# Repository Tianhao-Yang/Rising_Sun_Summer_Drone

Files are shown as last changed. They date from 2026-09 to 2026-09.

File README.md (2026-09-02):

# Rising Sun Summer Drone

Rising Sun is a self-built quadcopter developed as a summer engineering project. It combines mechanical design, flight control, onboard computing, telemetry, data logging, and a custom ground-station system.

This repository contains three main components:

1. Ground station
2. CAD files
3. Raspberry Pi onboard system

## 1. Ground Station

The ground-station system includes a desktop application and an online website.

### Desktop Application

The desktop application was developed using Python and PySide6. It receives MAVLink telemetry from the Pixhawk and live video from the onboard camera through a VTX system.

The application is organized into three pages:

- **Home:** Project overview, interactive 3D drone model, flight-log list, recorded videos, and telemetry-data viewer.
- **Flight Display:** Live camera feed, with a HUD display, flight instruments, motor and battery monitoring, system status, flight-phase checklists, warnings, recording controls and map.
- **HUD:** Enlarged flight interface showing the camera feed and HUD display, also showing flight-phase checklists, warnings, and map.  

The application records the Flight Display, HUD, camera feed, and telemetry data. These files are organized into individual flight logs together synchronized with onboard logs received from the Raspberry Pi through Bluetooth.

### Online Website

The Flask-based website is the public version of the desktop application. It includes:

- A project overview and interactive 3D drone model
- Published flight logs and telemetry data together with recorded flight display, HUD, and camera videos
- Live video views when the desktop application is online

The website is aiming to demonstrates the project and shares flight experiences with the public.
Website: https://red-sun-public-site.onrender.com/

## 2. CAD Files

The drone and its custom components were designed in SolidWorks. This section includes:

- Complete drone assembly
- Structural, motor, and electronics components
- Custom connection and mounting parts for 3D printing
- Exported 3D models used by the application and website

## 3. Onboard System

The onboard system runs on a Raspberry Pi connected to the Pixhawk. It:

- Reads and records MAVLink flight data
- Monitors Raspberry Pi temperature and resource usage
- Manages the **Before Takeoff**, **Cruising**, and **After Landing** phases
- Indicates the current flight phase through onboard LEDs
- Transfers flight logs to the desktop application through Bluetooth

## System Overview

The Pixhawk controls and stabilizes the aircraft. The Raspberry Pi manages onboard monitoring, flight states, and telemetry logging. The desktop application displays and records flight information, while the website publishes selected flight records for public viewing.

## Project Status

The drone, onboard computer, telemetry system, desktop application, and website have been integrated. Flight testing and system improvements are ongoing.

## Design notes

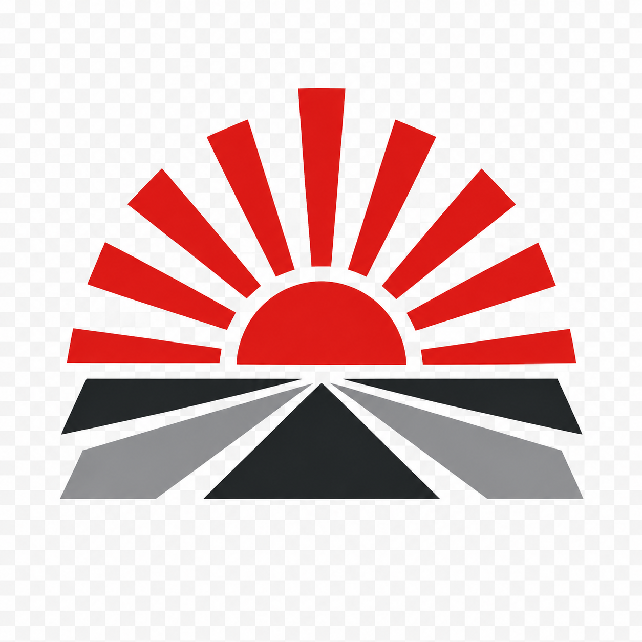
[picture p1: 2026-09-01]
Ground_Station/assets/RisingSun.png

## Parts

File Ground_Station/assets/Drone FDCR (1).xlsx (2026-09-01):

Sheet: Weight Estimation
 | System | Components | Weight(g) Estimation | Youtube 1 weight | Youtube 1 components
Drone | Mechanical system | frame | 630 | 630 | Upgrade ZD550 550mm
 |  | foam | 60 | 60
 |  | cover | 200 | 200
 |  | shock mount | 15 | 15
 | Electrical system | Battery | 700 | 900 | MaxAmps 6500mAh 4S LiPo Battery https://maxamps.com/products/lipo-6500-4s2p-14-8v-battery-pack
 |  | Power module | 60 | 60
 |  | Controller Receiver | 20 | 20
 |  | Pixhawk | 100 | 200 | HAWK’S WORK Pixhawk PX4 Flight Controller
 |  | PDB | 30 | 50 | ( need to have washer)
 |  | ESC*4 | 150 | 104
 |  | Motor | 900 | 432 | KDE Direct 2315XF-885KV 14P https://www.kdedirect.com/products/kde2315xf-885?_pos=1&_sid=3e5845d09&_ss=r | https://unmannedrc.com/products/unmannedrc-x550-quadcopter-educational-or-diy-full-kit?variant=45092810817733
 |  | DC-DC | 30 | 30
 |  | Pi | 125 | 100 | Breakout Board for Teensy 4.0 Module 33 Pins 3.81mm / 0.15" Screw Terminal Expansion Board 3 Types Output Compatible for Arduino | https://www.amazon.ca/TYXTTGY-ZD550-550mm-Carbon-Quadcopter/dp/B0F5WLPBWK
 |  | Navi light *4 | 4 | 4
 |  | Strobe light*4 | 4 | 4
 |  | Beacon light*2 | 4 | 4
 |  | Landing light*2 | 4 | 4
 |  | Buzzer | 5 | 5
 |  | Camera | 15 | 15
 |  | VTX | 15 | 15
 |  | Lidar | 10 | 25 | Ultrasonic Sensor
 | Software system | Ardu Pilot | 0 | 0
 |  | Pi FSM | 0 | 0
 |  |  | 3081 | 2877

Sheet: Diverging & converging_1
Motor | Price | Propeller | Voltage | Current | Thrust | Weight | Max Battery | ESC | Hover Current = 750g | Hover current total | Battery | Battery | Voltage | Capacity | Weight
https://sunnyskyusa.com/collections/all-motors/products/sunnysky-x2220 | 30 | APC9060 | 4S | 25.8 | 1400 | 85 | 3S-4S | 40A | 9.7 | 54.34 | 23547.33333 | https://genstattu.com/tattu-g-tech-4s-22000mah-14-8v-25c-lipo-battery-with-xt90-s-plug-for-uav/ | 4S | 22000mAh | 2450 | 25C
 |  |  |  | 28.6 | 1536 |  |  |  |  |  |  | https://genstattu.com/tattu-16000mah-30c-14-8v-4s-lipo-battery-pack-with-xt90s-f-plug/ | 4S | 16000mAh | 1590 | 30C | Battery | Motors | Propeller | ESC
 |  | APC1047 | 4S | 21.2 | 1400 |  |  |  | 8.65 | 37.6 | 16293.33333 | https://chinahobbyline.com/collections/uav-battery/products/cnhl-20000mah-14-8v-4s-15c-lipo-battery-with-xt90-plug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 | 4S | 20000mAh | 1560 | 15C | 4S 20000mAh 1560g | https://sunnyskyusa.com/collections/all-motors/products/sunnysky-x2814 | ？ | https://epicfpv.ca/products/talon-40a-slim-esc-blheli_32-f3-mcu
 |  |  |  | 23.2 | 1500 |  |  |  |  |  |  | https://chinahobbyline.com/collections/uav-battery/products/cnhl-16000mah-14-8v-4s-15c-lipo-battery-with-xt90-plug | 4S | 16000mAh | 1270 | 15C |  | https://sunnyskyusa.com/collections/multirotor-motors/products/sunnysky-v2814-motors
 |  |  |  | 26.1 | 1600 |  |  |  |  |  |  |  |  |  |  |  | 4S 16000mAh 1270g | https://sunnyskyusa.com/collections/all-motors/products/sunnysky-x2814-brushless-motors |  | https://www.hobbywingdirect.com/products/xrotor-40a-esc?variant=955949541
 |  |  |  | 29.3 | 1700 |  |  |  |  |  |  |  |  |  |  |  |  | https://sunnyskyusa.com/collections/all-motors/products/sunnysky-x2820-brushless-motors
 |  |  |  | 35 | 1900
 |  |  |  | 38.4 | 2130
 |  | APC9045 | 4S | 21.4 | 1400 |  |  |  | 8.96 | 38.84 | 16830.66667
 |  |  |  | 23.6 | 1506
 |  | APC9047 | 4S | 22.1 | 1450 |  |  |  | 8.9 | 38.6 | 16726.66667
SunnySky X Series V3 X2814 V3 Brushless Motors (https://sunnyskyusa.com/collections/all-motors/products/sunnysky-x2814) | 40 | APC11*5.5 | 4S | 19.1 | 1500 | 108 | 3S-4S | 40A-60A | 7 | 31 | 13433.33333
 |  |  |  | 25.3 | 1750
 |  |  |  | 30.5 | 2000
 |  |  |  | 37.2 | 2299
 |  | APC11*8 | 4S | 22.3 | 1500 |  |  |  | 8.3 | 36.2 | 15686.66667
 |  |  |  | 28.8 | 1750
 |  |  |  | 34.5 | 2000
 |  |  |  | 45.5 | 2320
https://sunnyskyusa.com/collections/all-motors/products/sunnysky-x2814-brushless-motors | 30 | APC11*7 | 4S | 22.4 | 1500 | 108 | 3S-4S | 40A | 8.1 | 35.4 | 15340
 |  |  |  | 28.2 | 1750
 |  |  |  | 34.4 | 2020
 |  | APC11*5.5 | 4S | 20.6 | 1500 |  |  |  | 7.9 | 34.6 | 14993.33333
 |  |  |  | 25.7 | 1750
 |  |  |  | 29.3 | 1950
 |  | APC11*8 | 4S | 23.7 | 1500 |  |  |  | 8.7 | 37.8 | 16380
 |  |  |  | 30.6 | 1750
 |  |  |  | 37.5 | 2020
https://sunnyskyusa.com/collections/all-motors/products/sunnysky-x2820-brushless-motors | 35 | APC13*6.5 | 4S | 17.9 | 1500 | 138 | 3S-5S | 60A
 |  |  |  | 22.2 | 1750
 |  |  |  | 27.2 | 2000
 |  |  |  | 33.1 | 2250
 |  |  |  | 37.5 | 2500
 |  |  |  | 40.1 | 2670
 |  | APC12*6 | 4S | 18.7 | 1500
 |  |  |  | 23.2 | 1750
 |  |  |  | 28.1 | 2000
 |  |  |  | 32.7 | 2240
 |  | APC13*8 | 4S | 19 | 1500
 |  |  |  | 23.7 | 1750
 |  |  |  | 28.9 | 2000
 |  |  |  | 35.5 | 2250
 |  |  |  | 40.2 | 2500
 |  |  |  | 45.2 | 2790
https://sunnyskyusa.com/collections/multirotor-motors/products/sunnysky-x3108s-motors | 25 | APC1038 | 4S | 23 | 1420 | 81 | 3S-4S | (40A) | 7.17 | 31.68 | 13728
 |  |  |  | 27 | 1530
 |  | APC1147 | 4S | 23 | 1410 |  |  |  | 7 | 31 | 13433.33333
 |  |  |  | 26 | 1490
 |  |  |  | 30 | 1580
https://sunnyskyusa.com/collections/multirotor-motors/products/sunnysky-v2814-motors | 35 | APC11*4.7 | 4S | 20.5 | 1600(100%) | 120 | 3S-5S | (30A) | 7 -> 830g | 31 | 13433.33333
 |  | APC12*3.8 |  | 18.6 | 1530(85%) |  |  |  | 6.4 | 28.6 | 12393.33333
 |  |  |  | 25.3 | 1810(100%)
 |  | APC13*4 |  | 13.5 | 1400(85%) |  |  |  | 5.7 -> 790g | 25.8 | 11180
 |  |  |  | 17.7 | 1660(100%)
 |  | APC15*4 |  | 14 | 1460(65%) |  |  |  | 5.1 | 23.4 | 10140
 |  |  |  | 18.5 | 1720(85%)
 |  |  |  | 23.4 | 1980(100%)
 |  | APC11*4.7 | 5S | 15.9 | 1580(75%) |  |  |  | 6.7 -> 920g | 29.8 | 12913.33333
 |  |  |  | 21.4 | 1840(85%)
 |  |  |  | 27 | 2130(100%)
 |  | APC13*4 |  | 14.2 | 1650(75%) |  |  |  | 5.3 -> 850g | 24.2 | 10486.66667
 |  |  |  | 18.1 | 1920(85%)
 |  |  |  | 23.7 | 2300(100%)
https://www.hobbywingdirect.com/collections/uav-system/products/xrotor-fpv-2807-motors?variant=42186475339891 | 28 |  | 4-6S | 56.7A/6S | 2810(1300KV) | 59 | 4-6S | (60A) | HQ7×3.5×3 prop: 8.5 HQ7×4×3 prop: 8.8
 |  |  | 4-5S | 59.5A/7S | 2646(1500KV) | 58.7 | 4-5S
 |  |  | 3-4S | 53.5A/13S | 2205(1700KV) | 58.4 | 3-4S
ESC | Price | Current | Telemetry | Power | Weight
https://www.hobbywingdirect.com/products/xrotor-40a-esc?variant=955949541 | 26 | 40A/60AMax | No | 2S-6S | 26g
https://epicfpv.ca/products/talon-40a-slim-esc-blheli_32-f3-mcu | 20 | 40A/60AMax | Yes | 3S-6S | 6.8g | Aircooler
https://www.hobbywing.com/en/products/xrotor-fpv-g2-45a-4in1-esc
https://holybro.com/products/tekko32-f4-4in1-50a-esc

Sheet: Diverging & converging_2
Battery | Battery Description | Motors | Motors Description | ESCs | ESC Description | Drone Weight | Single motor Max thrust | Hover thrust | Propeller | Hover Motor Current | Hover Total Current | Hovering Time
https://chinahobbyline.com/collections/uav-battery/products/cnhl-20000mah-14-8v-4s-15c-lipo-battery-with-xt90-plug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 | Voltage: 4S Capacity: 20000mAh Weight: 1560g 15C | https://sunnyskyusa.com/collections/all-motors/products/sunnysky-x2814 | Weight: 108g Voltage: 4S Max Thrust: 2299(APC11*5.5) MaxT = 65, 10min | https://epicfpv.ca/products/talon-40a-slim-esc-blheli_32-f3-mcu | Current: 40A/60A Max Telemetry: Yes Voltage: 3S-6S Weight: 6.8g | 3463g~3500g | 1750g | 875g | APC11*5.5 | 8.9 | 50.18 | 16.73973695
 |  |  | Weight: 108g Voltage: 4S Max Thrust: 2320(APC11*8) MaxT = 94, 3min |  |  |  |  |  | APC11*8 | 10.3 | 57.46 | 14.6188653
 |  |  | Weight: 108g Voltage: 4S Max Thrust: 2299(APC11*5.5) MaxT = 65, 10min | https://www.hobbywingdirect.com/products/xrotor-40a-esc?variant=955949541 | Current: 40A/60A Max Telemetry: No Voltage: 2S-6S Weight: 26g | 3537g~3600g | 1800g | 900g | APC11*7 | 9.28 | 52.156 | 16.10552957
 |  |  | Weight: 108g Voltage: 4S Max Thrust: 2320(APC11*8) MaxT = 94, 3min |  |  |  |  |  | APC11*5.5 | 10.7 | 59.54 | 14.10816258
 |  | https://sunnyskyusa.com/collections/multirotor-motors/products/sunnysky-v2814-motors | Weight: 120g Voltage: 4S Max Thrust: 1810(APC12*3.8) MaxT = 70 | https://epicfpv.ca/products/talon-40a-slim-esc-blheli_32-f3-mcu | Current: 40A/60A Max Telemetry: Yes Voltage: 3S-6S Weight: 6.8g | 3511g~3550g | 1775g | 888g | APC12*3.8 | 7.6 | 43.42 | 19.34592354
 |  |  | Weight: 120g Voltage: 4S Max Thrust: 1980(APC15*4) MaxT = 70 |  |  |  |  |  | APC15*4 | 6.7 | 38.74 | 21.68301497
 |  | https://sunnyskyusa.com/collections/all-motors/products/sunnysky-x2814-brushless-motors | Weight: 108g Voltage: 4S Max Thrust: 2020(APC11*7) MaxT = 61 | https://epicfpv.ca/products/talon-40a-slim-esc-blheli_32-f3-mcu | Current: 40A/60A Max Telemetry: Yes Voltage: 3S-6S Weight: 6.8g | 3463g~3500g | 1750g | 875g | APC11*7 | 10.25 | 57.2 | 14.68531469
 |  |  | Weight: 108g Voltage: 4S Max Thrust: 1950(APC11*5.5) MaxT = 48 |  |  |  |  |  | APC11*5.5 | 9.8 | 54.86 | 15.31170252
 |  |  | Weight: 108g Voltage: 4S Max Thrust: 1950(APC11*5.5) MaxT = 59 |  |  |  |  |  | APC11*8 | 10.85 | 60.32 | 13.92572944
 |  |  | Weight: 108g Voltage: 4S Max Thrust: 2020(APC11*7) MaxT = 61 | https://www.hobbywingdirect.com/products/xrotor-40a-esc?variant=955949541 | Current: 40A/60A Max Telemetry: No Voltage: 2S-6S Weight: 26g | 3537g~3600g | 1800g | 900g | APC11*7 | 10.68 | 59.436 | 14.13284878
 |  |  | Weight: 108g Voltage: 4S Max Thrust: 1950(APC11*5.5) MaxT = 48 |  |  |  |  |  | APC11*5.5 | 10.18 | 56.836 | 14.77936519
 |  |  | Weight: 108g Voltage: 4S Max Thrust: 1950(APC11*5.5) MaxT = 59 |  |  |  |  |  | APC11*8 | 11.28 | 62.556 | 13.42796854
https://chinahobbyline.com/collections/uav-battery/products/cnhl-16000mah-14-8v-4s-15c-lipo-battery-with-xt90-plug | Voltage: 4S Capacity: 16000mAh Weight: 1270g 15C | https://sunnyskyusa.com/collections/all-motors/products/sunnysky-x2814 | Weight: 108g Voltage: 4S Max Thrust: 2299(APC11*5.5) MaxT = 65, 10min | https://epicfpv.ca/products/talon-40a-slim-esc-blheli_32-f3-mcu | Current: 40A/60A Max Telemetry: Yes Voltage: 3S-6S Weight: 6.8g | 3137g~3200g | 1600g | 800g | APC11*5.5 | 7.76 | 44.252 | 15.18575432
 |  |  | Weight: 108g Voltage: 4S Max Thrust: 2320(APC11*8) MaxT = 94, 3min |  |  |  |  |  | APC11*8 | 9.1 | 51.22 | 13.11987505
 |  |  | Weight: 108g Voltage: 4S Max Thrust: 2299(APC11*5.5) MaxT = 65, 10min | https://www.hobbywingdirect.com/products/xrotor-40a-esc?variant=955949541 | Current: 40A/60A Max Telemetry: No Voltage: 2S-6S Weight: 26g | 3274g~3300g | 1650g | 825g | APC11*5.5 | 8.14 | 46.228 | 13.11987505
 |  |  | Weight: 108g Voltage: 4S Max Thrust: 2320(APC11*8) MaxT = 94, 3min |  |  |  |  |  | APC11*8 | 9.5 | 53.3 | 12.60787992
 |  | https://sunnyskyusa.com/collections/multirotor-motors/products/sunnysky-v2814-motors | Weight: 120g Voltage: 4S Max Thrust: 1810(APC12*3.8) MaxT = 70 | https://epicfpv.ca/products/talon-40a-slim-esc-blheli_32-f3-mcu | Current: 40A/60A Max Telemetry: Yes Voltage: 3S-6S Weight: 6.8g | 3137g~3200g | 1600g | 800g | APC12*3.8 | 6.4 | 37.18 | 18.07423346
 |  |  | Weight: 120g Voltage: 4S Max Thrust: 1980(APC15*4) MaxT = 70 |  |  |  |  |  | APC15*4 | 5.68 | 33.436 | 20.09809786
 |  | https://sunnyskyusa.com/collections/all-motors/products/sunnysky-x2814-brushless-motors | Weight: 108g Voltage: 4S Max Thrust: 2020(APC11*7) MaxT = 61 | https://epicfpv.ca/products/talon-40a-slim-esc-blheli_32-f3-mcu | Current: 40A/60A Max Telemetry: Yes Voltage: 3S-6S Weight: 6.8g | 3137g-3200g | 1600g | 800g | APC11*7 | 8.69 | 49.088 | 13.68970013
 |  |  | Weight: 108g Voltage: 4S Max Thrust: 1950(APC11*5.5) MaxT = 48 |  |  |  |  |  | APC11*5.5 | 8.66 | 48.932 | 13.73334423
 |  |  | Weight: 108g Voltage: 4S Max Thrust: 1950(APC11*5.5) MaxT = 59 |  |  |  |  |  | APC11*8 | 9.56 | 53.612 | 12.5345072
 |  |  | Weight: 108g Voltage: 4S Max Thrust: 2020(APC11*7) MaxT = 61 | https://www.hobbywingdirect.com/products/xrotor-40a-esc?variant=955949541 | Current: 40A/60A Max Telemetry: Yes Voltage: 3S-6S Weight: 26g | 3274g~3300g | 1650g | 825g | APC11*7 | 9.39 | 52.728 | 12.7446518
 |  |  | Weight: 108g Voltage: 4S Max Thrust: 1950(APC11*5.5) MaxT = 48 |  |  |  |  |  | APC11*5.5 | 9.04 | 50.908 | 13.20028286 |  | 额定电流 最大电流
 |  |  | Weight: 108g Voltage: 4S Max Thrust: 1950(APC11*5.5) MaxT = 59 |  |  |  |  |  | APC11*8 | 9.99 | 55.848 | 12.03266008
Battery | Battery Description | Motors | Motors Description | ESCs | ESC Description | Drone Weight | Single motor Max thrust | Hover thrust | Propeller | Hover Motor Current | Hover Total Current | Hovering Time | Max current
https://chinahobbyline.com/collections/uav-battery/products/cnhl-20000mah-14-8v-4s-15c-lipo-battery-with-xt90-plug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 | Voltage: 4S Capacity: 20000mAh Weight: 1560g 15C | https://sunnyskyusa.com/collections/multirotor-motors/products/sunnysky-v2814-motors | Weight: 120g Voltage: 4S Max Thrust: 1810(APC12*3.8) MaxT = 70 | https://epicfpv.ca/products/talon-40a-slim-esc-blheli_32-f3-mcu | Current: 40A/60A Max Telemetry: Yes Voltage: 3S-6S Weight: 6.8g | 3511g~3550g | 1775g | 888g | APC12*3.8 | 7.6 | 43.42 | 19.34592354 | 135.46
https://chinahobbyline.com/collections/uav-battery/products/cnhl-16000mah-14-8v-4s-15c-lipo-battery-with-xt90-plug | Voltage: 4S Capacity: 16000mAh Weight: 1270g 15C | https://sunnyskyusa.com/collections/multirotor-motors/products/sunnysky-v2814-motors | Weight: 120g Voltage: 4S Max Thrust: 1810(APC12*3.8) MaxT = 70 | https://epicfpv.ca/products/talon-40a-slim-esc-blheli_32-f3-mcu | Current: 40A/60A Max Telemetry: Yes Voltage: 3S-6S Weight: 6.8g | 3137g~3200g | 1600g | 800g | APC12*3.8 | 6.4 | 37.18 | 18.07423346 | 135.46

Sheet: Diverging &converging_3
 | System | Components | Link | Weight |  |  | Specifications
Drone | Mechanical system | frame | https://www.aliexpress.com/item/1005004062843638.html | 630 | Analog video transmitter | https://www.amazon.ca/Koarmy-5-8Ghz-Wireless-Transmitter-1000TVL/dp/B0D76KDKB1 | 5.8Ghz 2W 20Km 64.5g
 |  | foam |  |  |  | https://www.amazon.ca/Transmitter-700TVL-Degree-Camera-Quadcopter/dp/B01N5A6SHM | 5.8Ghz 600mW 3Km 28.35g
 |  | cover |  |  |  | https://www.aliexpress.com/item/1005008470126543.html | 5.8Ghz 1w 2-5Km 60g Powered by 2-4S via JST connector by default 4 levels of adjustable power: 100mW, 200mW, 400mW, and 1000mW VTX: 7-26V DC Camera: 5V DC
 |  | shock mount | https://www.aliexpress.com/item/1005008007238497.html | 24 | RC signal transmitting range | https://radiomasterrc.com/collections/receivers/products/rp3-expresslrs-2-4ghz-nano-receiver | 2.4Ghz ELRS 2 antenna
 | Electrical system | Battery | https://chinahobbyline.com/collections/uav-battery/products/cnhl-20000mah-14-8v-4s-15c-lipo-battery-with-xt90-plug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 | 1560 | Telemetry radio | https://www.aliexpress.com/item/1005006542476053.html | 915Mhz 1000mW
 |  | Power module | https://www.aliexpress.com/item/1005008280978116.html?src=google | 20 | Pixhawk |  | 6C Max input voltage: 6V USB power input: 4.75~5.25V servo rail input: 0-36V TELEM1 Max output current limiter: 1.5A All other port combined output current limiter: 1.5A 33g
 |  | Controller Receiver | https://www.amazon.ca/Vernijtrdy-Receiver-2-4GHZ-Aircraft-Reception/dp/B0DWN2WT85 | 4.6 | Power module |  | Voltage: 2S-12S PCB Cont. Current Rating: 60A PCB Burst Current Rating: 100A(<60sec) Max Current Sensing: 120A Output: DC 5.2V & 3A Max Voltage Divider: 18.182 Amperes per Volt: 36.364
 |  | Pixhawk | https://www.aliexpress.com/item/1005008007238497.html | 150 | Buzzer
 |  | PDB |  |  | GPS |  | M9N Accuracy: 1.5m
 |  | ESC*4 | https://epicfpv.ca/products/talon-40a-slim-esc-blheli_32-f3-mcu | 27.2 | Pi | https://www.pishop.ca/product/raspberry-pi-4-model-b-4gb/?src=raspberrypi | 4GB
 |  | Motor*4 | https://sunnyskyusa.com/collections/all-motors/products/sunnysky-x2814-brushless-motors | 432 | PDB | https://www.aliexpress.com/item/33010633621.html | Voltage: 3S-4S BEC 5V 2A (2.5A 10sec) -> DC-DC BEC 12V -> VTX 6ESC output &1 pair VCC/GND pads
 |  | DC-DC | https://www.amazon.ca/ZORZA-Regulator-Antijamming-Switching-Quadcopter/dp/B0CQ1R55BV | 18 | DC-DC | https://www.aliexpress.com/i/33020848100.html | 5V， 5A
 |  | Pi | https://www.pishop.ca/product/raspberry-pi-4-model-b-4gb/?src=raspberrypi | 50
 |  | Navi light *4 | https://www.aliexpress.com/item/4000215177842.html | 53
 |  | Strobe light*4
 |  | Beacon light*2
 |  | Landing light*2
 |  | Buzzer | https://www.amazon.ca/RuiLing-Decibels-Continuous-Sounder-Electronic/dp/B07NK8MGL9 | 6
 |  | Camera | https://www.aliexpress.com/item/1005009369607974.html | 64
 |  | VTX
 |  | Lidar | https://www.aliexpress.com/item/32852024277.html | 5
 | Software system | Ardu Pilot
 |  | Pi FSM |  | 3043.8

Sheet: Product
 | Product |  | Description | Weight (g) | Price |  | Description | Weight | Price
Propotion system | Battery | https://chinahobbyline.com/collections/uav-battery/products/cnhl-16000mah-14-8v-4s-15c-lipo-battery-with-xt90-plug | "Voltage: 4S Capacity: 20000mAh 15C Weight: 1560g | 1270 | 186 | https://chinahobbyline.com/collections/uav-battery/products/cnhl-16000mah-14-8v-4s-15c-lipo-battery-with-xt90-plug |  |  | 1285
 | Motors | https://www.alibaba.com/product-detail/Tarot-700KV-Motor-TL68B17-Multi-axis_1601038988774.html | Weight: 120g Voltage: 4S Max Thrust: 1810(APC12*3.8) MaxT = 70" | 408 | 140 | https://item.taobao.com/item.htm?abbucket=6&id=745842377561&mi_id=0000WRAlEvrOvU-NPz0iO-UwB0ETkdphn DED2anIwpRKV1I&ns=1&priceTId=2150454917793804562808166e0fb9&skuId=5142216528925&spm=a21n57.1.hover Item.1&utparam=%7B%22aplus_abtest%22%3A%223cc33a16c2e12cf65a70a74454cee2a2%22%7D&xxc=taobaoSearch |  |  | 332
 | ESCs | Talon 40A Slim ESC Blheli_32 F3 MCU – EpicFPV (https://epicfpv.ca/products/talon-40a-slim-esc-blheli_32-f3-mcu) | Current: 40A/60A Max Telemetry: Yes Voltage: 3S-6S Weight: 6.8g | 27.2 | 80 | https://epicfpv.ca/products/talon-40a-slim-esc-blheli_32-f3-mcu?srsltid=AfmBOoprjATcpDmGpbVlsvSzOOGLmS9yg23n AjDTi-hEasocI55W90LT |  |  | 145
 | Propellar | https://www.apcprop.com/product/12x3-8sf-b4/?v=3e8d115eb4b3 | Weight: 18g APC 12* 3.8 | 18 | 15 | https://item.taobao.com/item.htm?ali_refid=a3_430620_1006%3A1268210151%3AH%3A4oc7A3p8TyJD93vx YufOSzVb5%2Bk6PK7i%3A85ac173ed714e57f1b8cd4023cd87e09&ali_trackid=283_85ac173ed714e57f1b8cd4023cd 87e09&id=1005300961105&mi_id=0000QJqRmBP2cOHzpjZDB7StR55auRdszExuX8X4h6EytKw&mm_sceneid=1_0_ 129748716_0&priceTId=2100c8df17793807938121052e0cea&skuId=6164042443797&spm=a21n57.1.hoverItem.1&ut param=%7B%22aplus_abtest%22%3A%2249cc4b11ce2521e003db9ae62a55138f%22%7D&xxc=ad_ztc (https://item.taobao.com/item.htm?ali_trackid=283_85ac173ed714e57f1b8cd4023cd87e09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) |  |  | 100
Control System | Pixhawk | https://www.aliexpress.com/item/1005006542476053.html | 6C Max input voltage: 6V USB power input: 4.75~5.25V servo rail input: 0-36V TELEM1 Max output current limiter: 1.5A All other port combined output current limiter: 1.5A 33g | 33 | 380 | https://item.taobao.com/item.htm?id=873609950755&pisk=gzhoYWqI3YyWmFj2sMPWnbskxW9xw7NQYDCLvWEe3orj y6LSyx4EvmTBP73UxDmYc4CpP4Hc-VimxJT7vkrnv2kJkCdtP4NQTBx96CEFDsMIxzPUUi8U5ySyk8oAQT88ThK96tQ 4F3FEJuA3jju4cyfPaToF3tz_0yWzTDr43PzO4WPEYEV48yazYzzPg-z80MSz4yu2gzUgYgzzzE04cPNUYDyyoqrb8WrE aYBzXXkZghMLRYu0_Xl0r8qZoI1FtazPXl0zh6f3qmeky4rcT6lmdRg-NuJ1kkN8V4UoAC17aJDsJymkZ_on5ji0ucRh6uuj WAeSapCTISrupbukqB0mtu2Za-bpWqV08DynhhfTr7H0IbDWRiurXuDaN2QM2q2inRa43wXzwA3tORlyZGZYCym8DcR NiSyF4CXVQCbGOr8Kg96QUra0XaqywmcRv0rMoEXtR8zb5lLDo96QUra0XEYcBXwzlPZO.&spm=pc_detail.30350276. guessitem.d2&skuId=5708268584687 |  |  | 1600
 | Telemetry Radio |  | 915Mhz 1000mW | 35
 | Power module |  | Voltage: 2S-12S PCB Cont. Current Rating: 60A PCB Burst Current Rating: 100A(<60sec) Max Current Sensing: 120A Output: DC 5.2V & 3A Max Voltage Divider: 18.182 Amperes per Volt: 36.364" | 20
 | Buzzer |  |  | 6
 | GPS |  | "M9N Accuracy: 1.5m" | 32
 | Pi | https://www.pishop.ca/product/raspberry-pi-4-model-b-4gb/?src=raspberrypi | 4GB | 60 | 139 | https://item.taobao.com/item.htm?abbucket=6&id=920742370781&mi_id=0000TsZZI4IkphOQHmaIwtVecBSioLO8yMP oRCiDbt77ZOU&ns=1&priceTId=215041d017793791320268689e0f65&skuId=5796315073733&spm=a21n57.1.hoverI tem.12&utparam=%7B%22aplus_abtest%22%3A%22ffd70e95a52f7cbd3e2908d7770af98d%22%7D&xxc=taobaoSearch |  |  | 856
 | PDB | https://www.aliexpress.com/item/33010633621.html | Voltage: 3S-4S BEC 5V 2A (2.5A 10sec) -> DC-DC BEC 12V -> VTX 6ESC output &1 pair VCC/GND pads | 20 | 7 | https://www.aliexpress.com/item/33010633621.html |  |  | 35
 | DC-DC | https://www.aliexpress.com/i/33020848100.html | 5V, 5A | 10 | 5 | https://www.aliexpress.com/i/33020848100.html |  |  | 25
 | Lights | https://www.aliexpress.com/item/4000215177842.html |  | 53 | 15 | https://www.aliexpress.com/item/4000215177842.html |  |  | 75
 | Lidar | https://www.aliexpress.com/item/32852024277.html |  | 6.1 | 28 | https://www.aliexpress.com/item/32852024277.html |  |  | 140
 | RC reveiver | https://radiomasterrc.com/collections/receivers/products/rp3-expresslrs-2-4ghz-nano-receiver | 2.4Ghz ELRS 2 antenna | 4.6 | 20 | https://item.taobao.com/item.htm?abbucket=6&id=753200908155&mi_id=0000CcY5rRV2k_CR1TKlmxUck4dAjgjAw- jEtZRf4Ml1Zsg&ns=1&priceTId=215046ae17793782071154520e0fde&skuId=5736209579616&spm=a21n57.1.hoverIte m.42&utparam=%7B%22aplus_abtest%22%3A%2229139f928278af91fea950879a716df4%22%7D&xxc=taobaoSearch |  |  | 130
 | Analog video transmitter | https://www.aliexpress.com/item/1005008470126543.html | 5.8Ghz 1w 2-5Km 60g Powered by 2-4S via JST connector by default 4 levels of adjustable power: 100mW, 200mW, 400mW, and 1000mW VTX: 7-26V DC Camera: 5V DC | 60 | 61 | https://www.aliexpress.com/item/1005008470126543.html |  |  | 305
Mechanical System | Frame | https://www.aliexpress.com/item/1005004062843638.html | frame size: 550 | 630 | 73 | https://www.taobao.com/list/item/798720065262.htm?spm=a21wu.11804641.shop-content.34.6cc466238IHCYS |  |  | 498
 |  |  |  | 2692.9 | 1149 |  |  |  | 7474

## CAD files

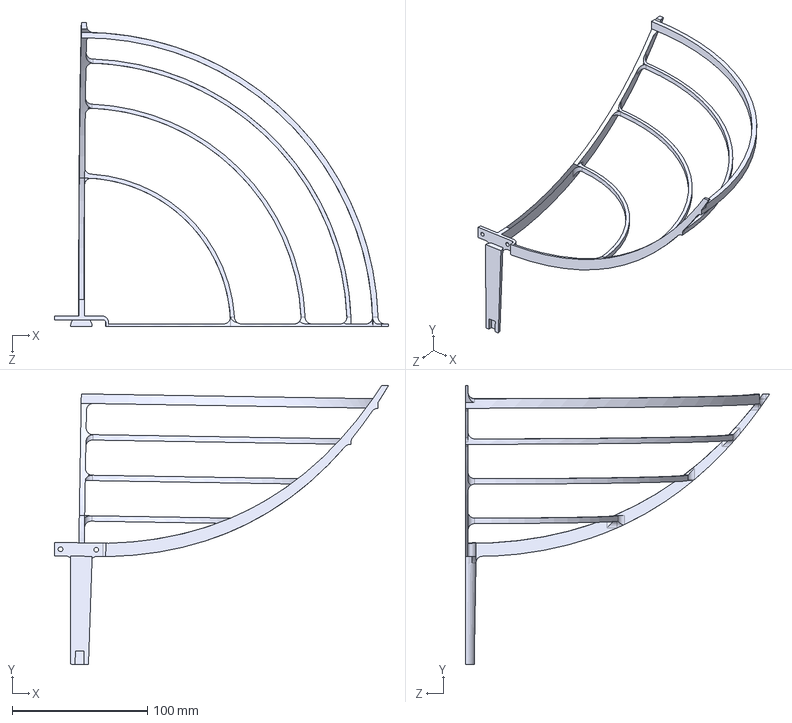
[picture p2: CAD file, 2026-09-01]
CAD/Connections/Part12-Split1.STEP
247.0 x 206.3 x 225.0 mm

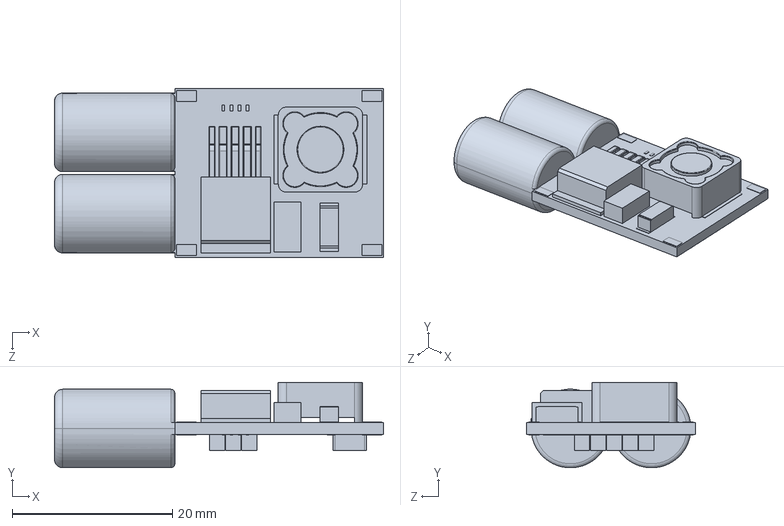
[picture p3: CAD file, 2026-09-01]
CAD/DC-DC/UBEC.step.SLDPRT
41.0 x 10.6 x 21.0 mm

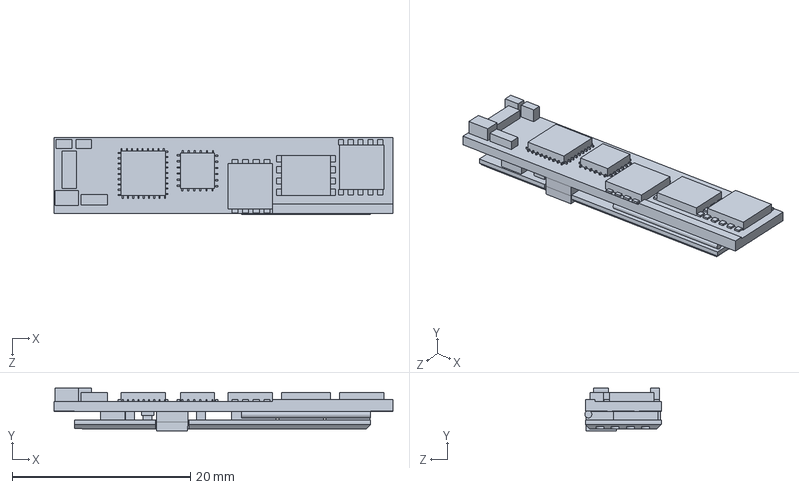
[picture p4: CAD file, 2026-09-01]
CAD/ESC/ESC.SLDPRT
38.0 x 4.80 x 8.58 mm

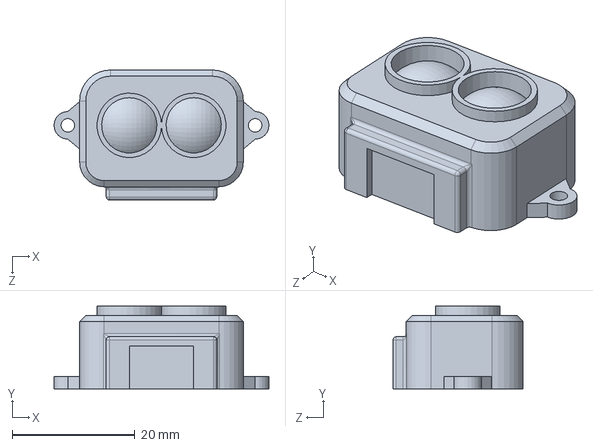
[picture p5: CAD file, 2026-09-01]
CAD/Lidar/Sensor LUNA.SLDPRT
35.0 x 13.5 x 21.1 mm

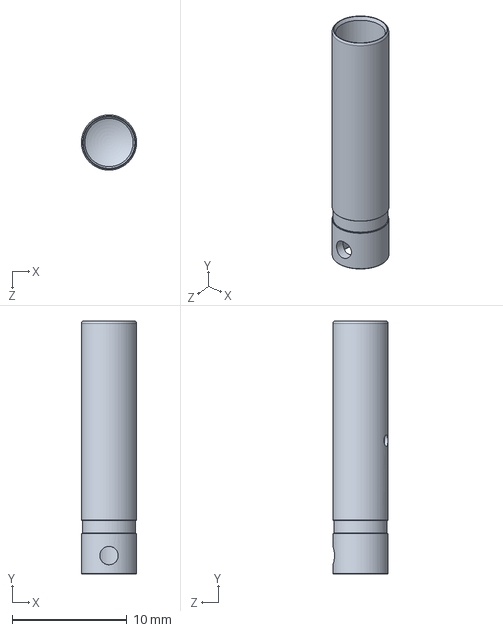
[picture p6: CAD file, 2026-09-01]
CAD/Motor/Bullet_Female_4mm.SLDPRT
4.80 x 22.0 x 4.80 mm

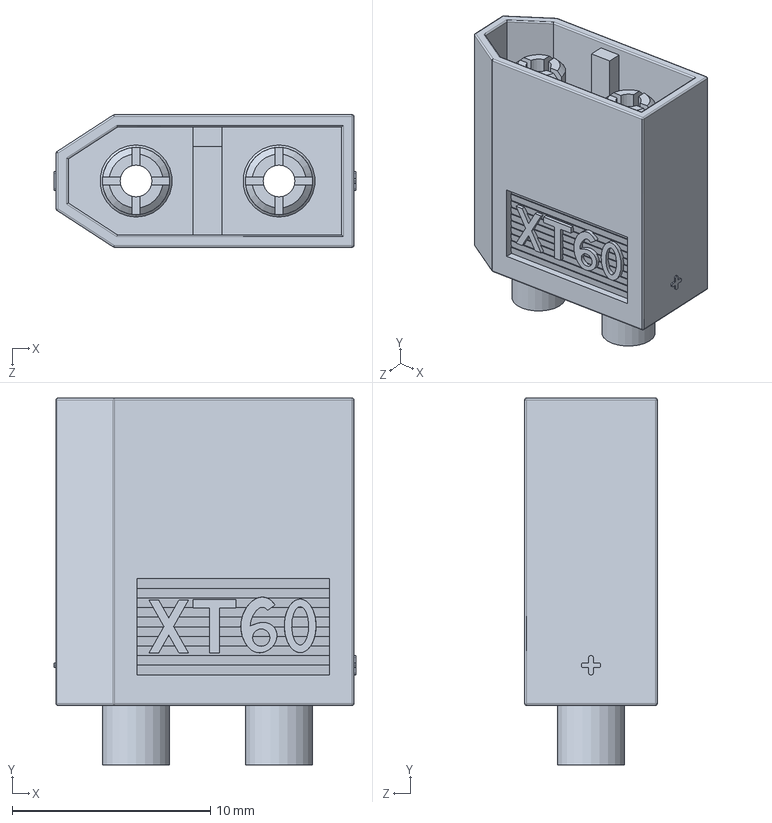
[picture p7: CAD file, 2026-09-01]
CAD/PDB/XT 60 male connector.SLDPRT
15.2 x 18.5 x 6.69 mm

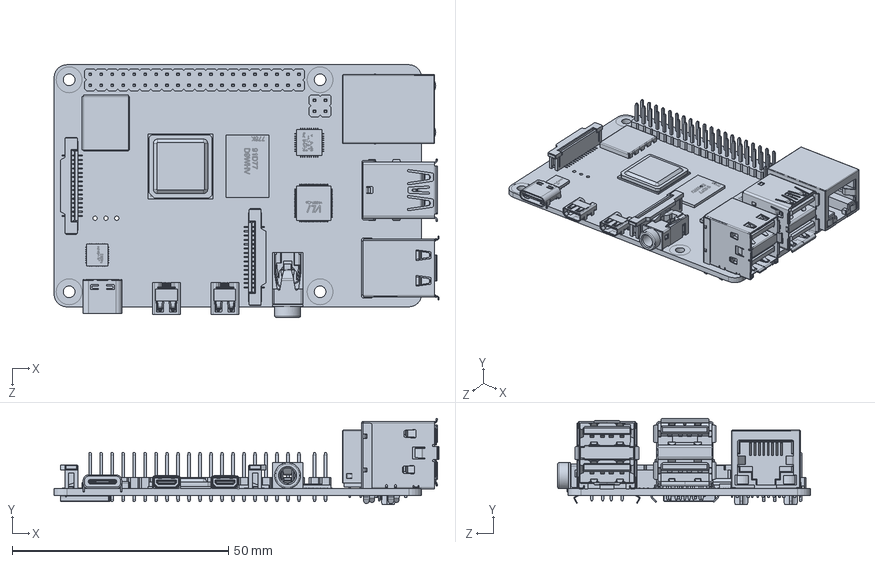
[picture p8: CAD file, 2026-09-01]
CAD/Pi/Raspberry Pi 4.SLDPRT
89.0 x 19.9 x 58.4 mm

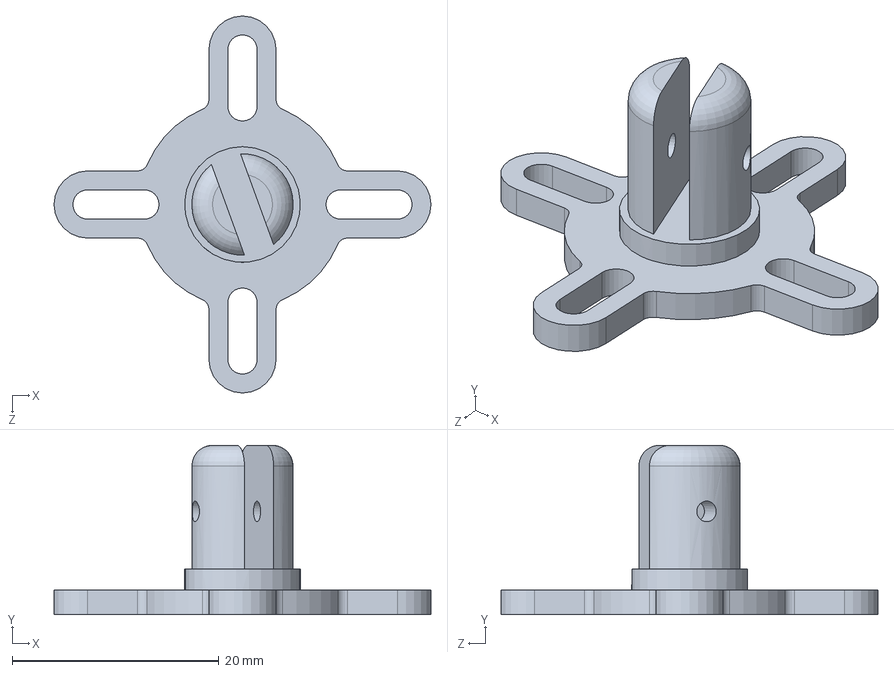
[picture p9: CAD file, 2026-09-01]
CAD/Pixhawk Kit/GPS/Base.SLDPRT
36.5 x 16.4 x 36.5 mm

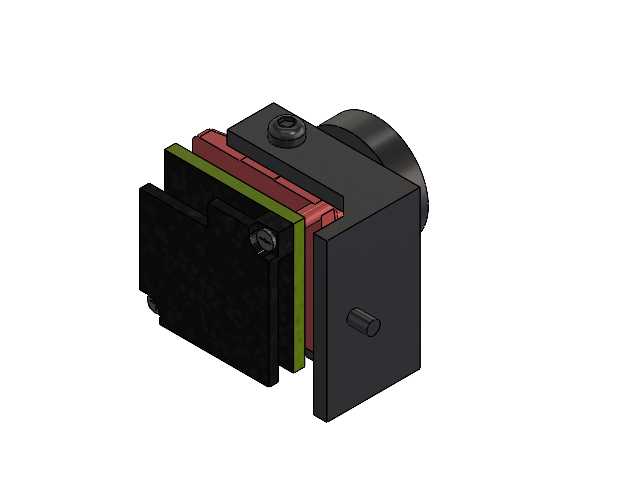
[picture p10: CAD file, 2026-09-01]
CAD/Camera & VTX/Camera.SLDASM
Part1-C
Part10-C x 2
Part2-C
Part3-C
Part4-C
Part5-C x 3

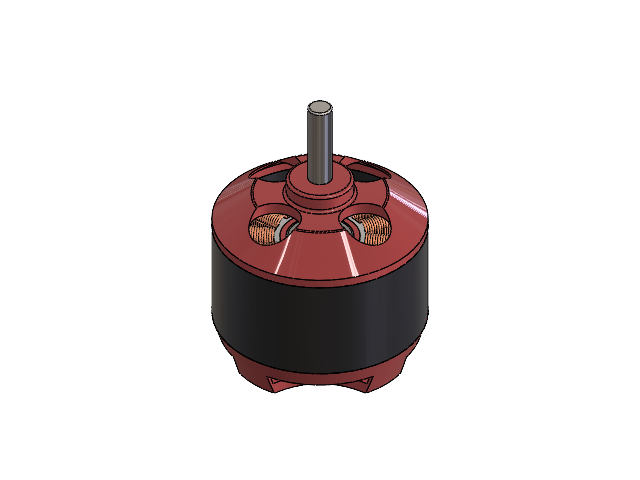
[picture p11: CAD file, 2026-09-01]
CAD/Motor/Motor.SLDASM
Stand
Stator
Cover
Axis
Head

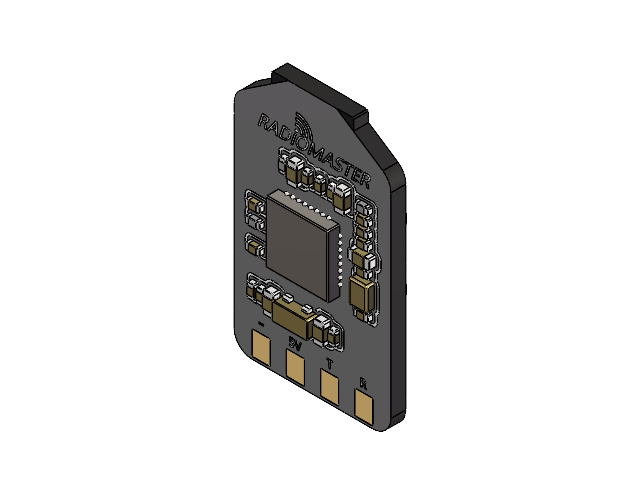
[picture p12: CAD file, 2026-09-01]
CAD/RC receiver/PCB _1_.SLDASM
PCB
PCB (1)

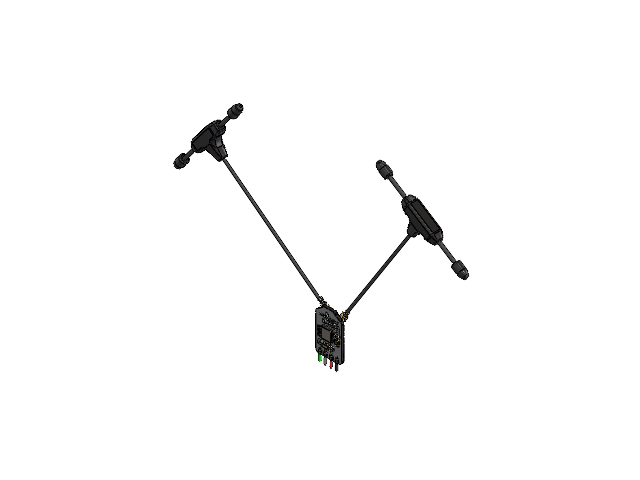
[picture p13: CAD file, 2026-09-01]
CAD/RC receiver/RC receiver Assembly.SLDASM
PCB
PCB (1)
u.Fl Antenna Connector - 523-A-1JB v1(Mirror)
u.Fl Antenna Connector - 523-A-1JB v1
Radiomaster RP3 Module
UFL IPEX Connector v1 x 2
Dipole T Antenna x 2
5V Wire
GND Wire
TX Wire
RX Wire

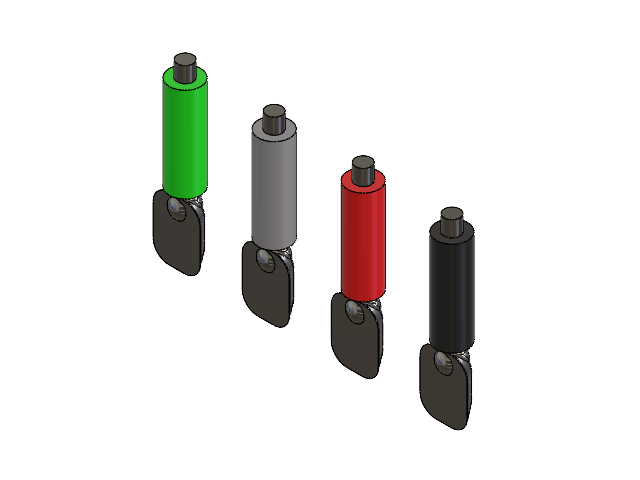
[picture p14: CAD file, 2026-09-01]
CAD/RC receiver/Wiring Head.SLDASM
5V Wire
GND Wire
TX Wire
RX Wire

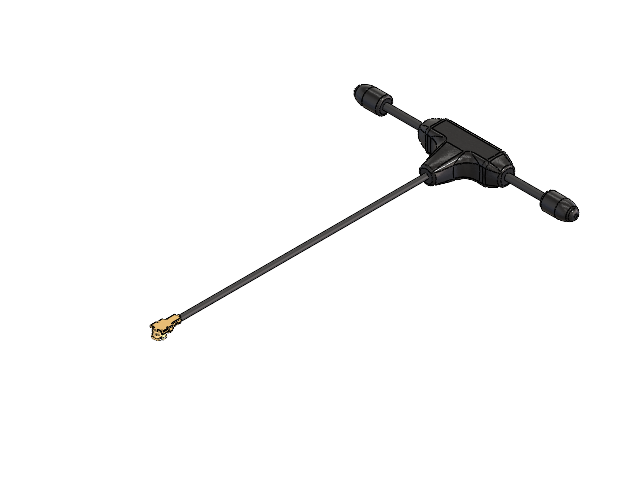
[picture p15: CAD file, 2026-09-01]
CAD/RC receiver/Antenna.SLDASM
UFL IPEX Connector v1
Dipole T Antenna

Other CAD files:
CAD/Camera & VTX/VTX.SLDASM
CAD/RC receiver/Module.SLDASM
CAD/ZD550 Frame/Frame Assembly.SLDASM
CAD/ZD550 New/Frame.SLDASM
CAD/Camera & VTX/Part1-C.SLDPRT
CAD/Camera & VTX/Part10-C.SLDPRT
CAD/Camera & VTX/Part11-C.SLDPRT
CAD/Camera & VTX/Part12-V.SLDPRT
CAD/Camera & VTX/Part13-V.SLDPRT
CAD/Camera & VTX/Part2-C.SLDPRT
CAD/Camera & VTX/Part3-C.SLDPRT
CAD/Camera & VTX/Part4-C.SLDPRT
CAD/Camera & VTX/Part5-C.SLDPRT
CAD/Camera & VTX/Part6-V.SLDPRT
CAD/Camera & VTX/Part7-V.SLDPRT
CAD/Camera & VTX/Part8-V.SLDPRT
CAD/Camera & VTX/Part9-V.SLDPRT
CAD/Connections/Part1.SLDPRT
CAD/Connections/Part1.STEP
CAD/Connections/Part10.SLDPRT
CAD/Connections/Part10.STEP
CAD/Connections/Part11.SLDPRT
CAD/Connections/Part11.STEP
CAD/Connections/Part12-Split1.SLDPRT
CAD/Connections/Part12-Split2.SLDPRT
CAD/Connections/Part12-Split2.STEP
CAD/Connections/Part12.SLDPRT
CAD/Connections/Part12.STEP
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

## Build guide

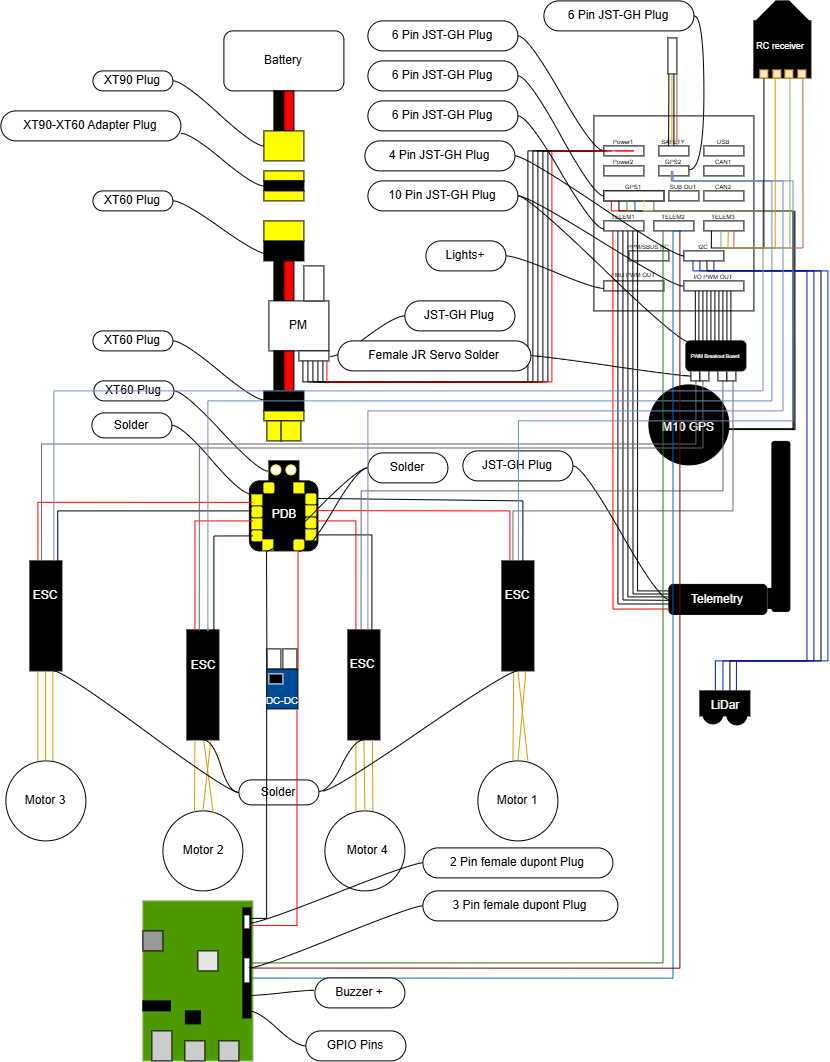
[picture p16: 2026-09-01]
Ground_Station/assets/Electrical Wiring.drawio.png

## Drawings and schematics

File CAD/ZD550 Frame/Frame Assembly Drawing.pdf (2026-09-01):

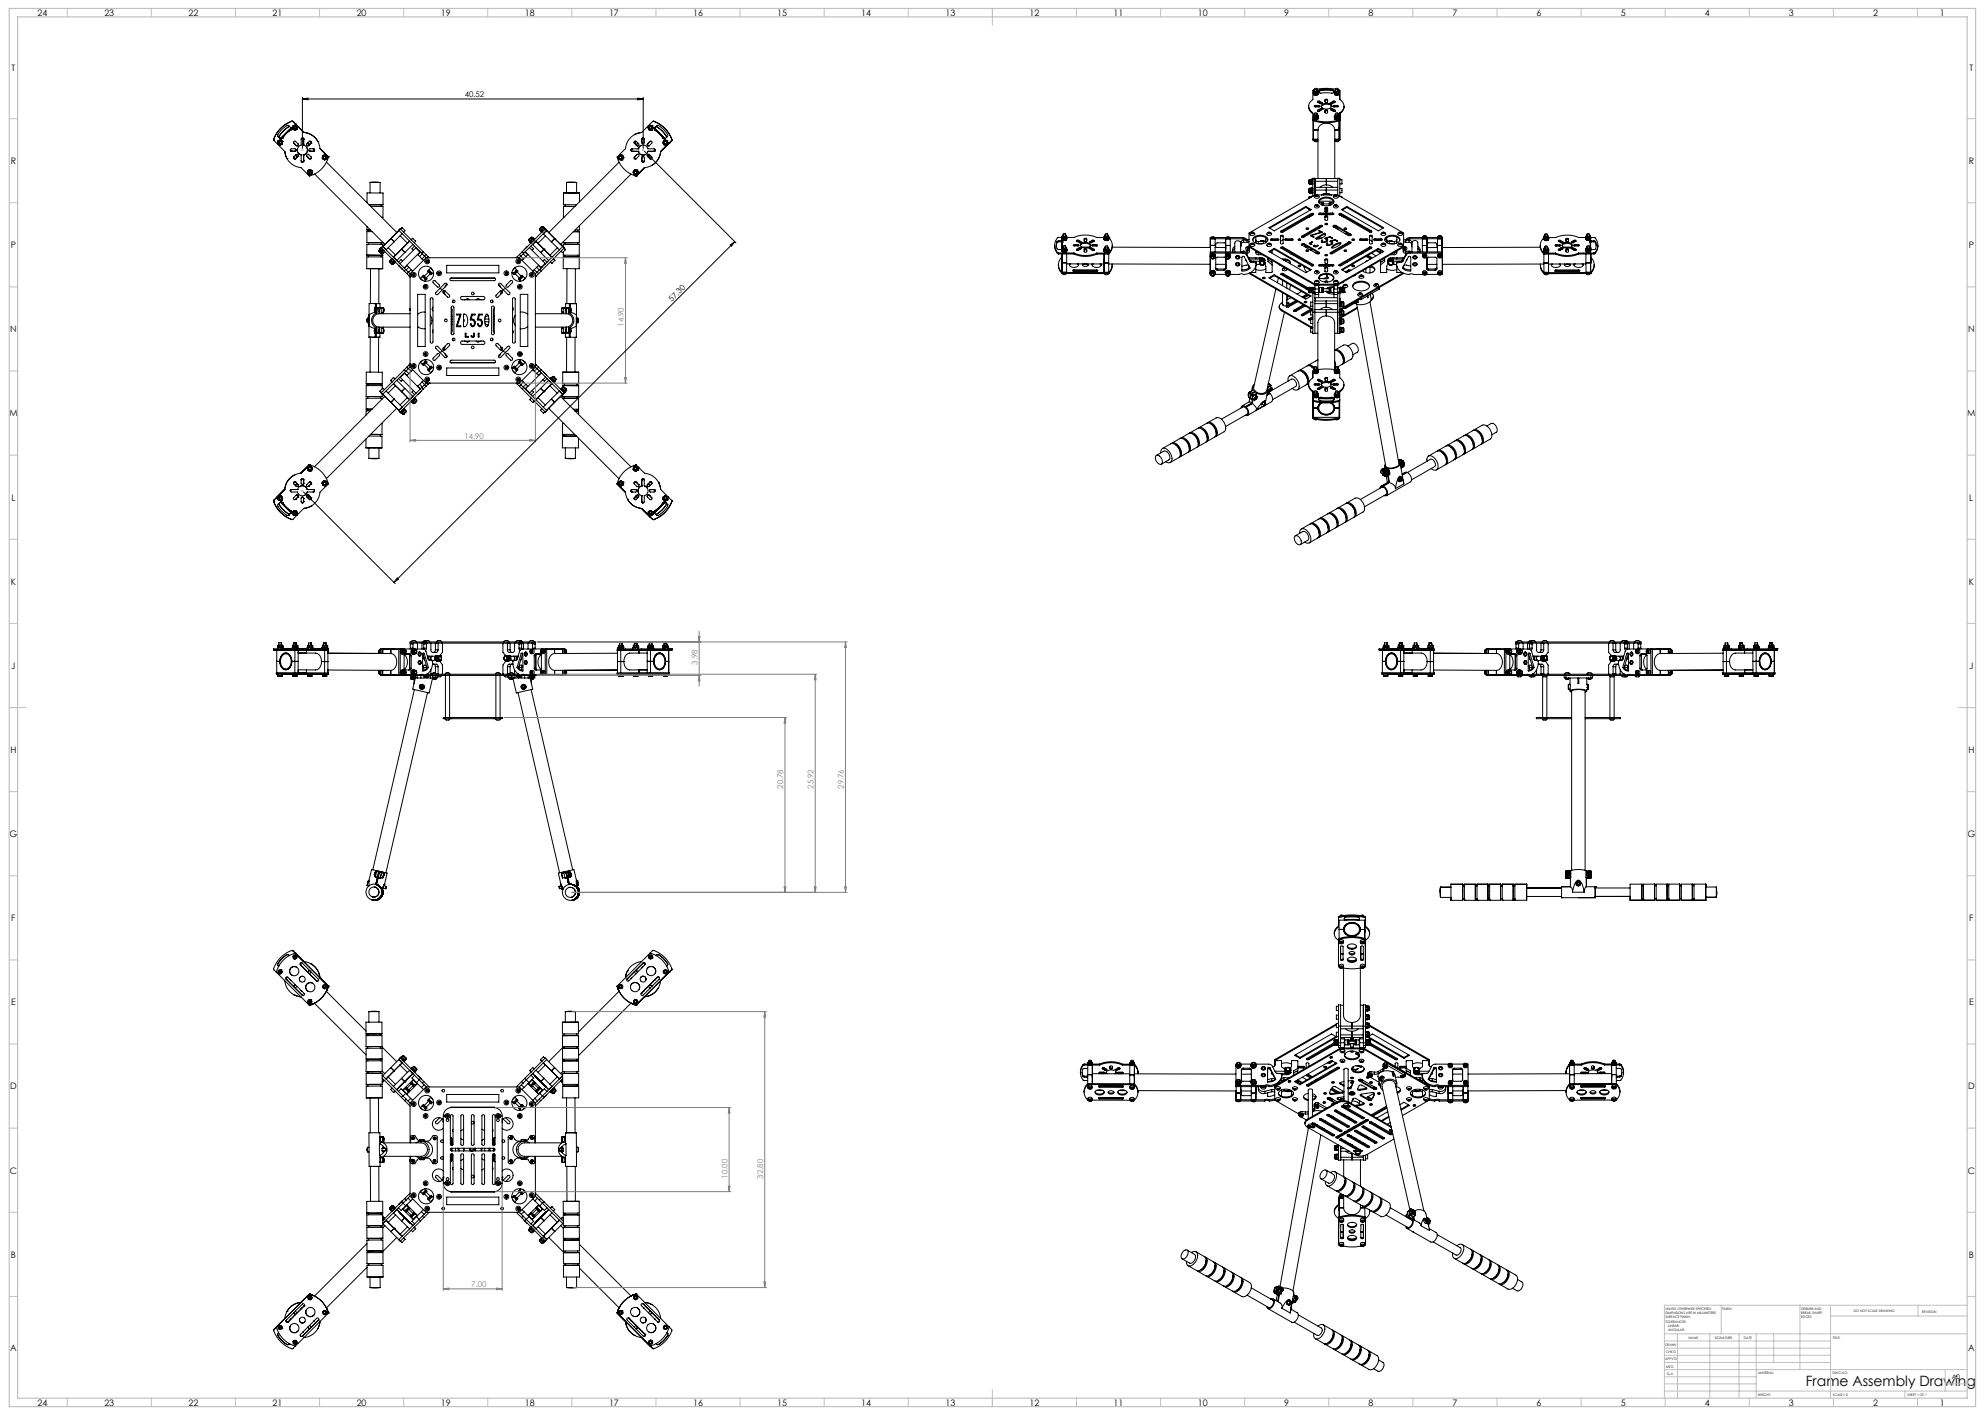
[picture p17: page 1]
FINISH:; DEBURR AND; BREAK SHARP; DO NOT SCALE DRAWING; REVISION; SCALE:1:2; SHEET 1 OF 1

UNLESS OTHERWISE SPECIFIED:
DIMENSIONS ARE IN MILLIMETERS
SURFACE FINISH:
TOLERANCES:
LINEAR:
ANGULAR:

NAME | SIGNATURE | DATE | | | | TITLE:

DRAWN
CHK'D
APPV'D
MFG
Q.A | | | | MATERIAL: Frame Assembly Drawing | DWG NO. | A0

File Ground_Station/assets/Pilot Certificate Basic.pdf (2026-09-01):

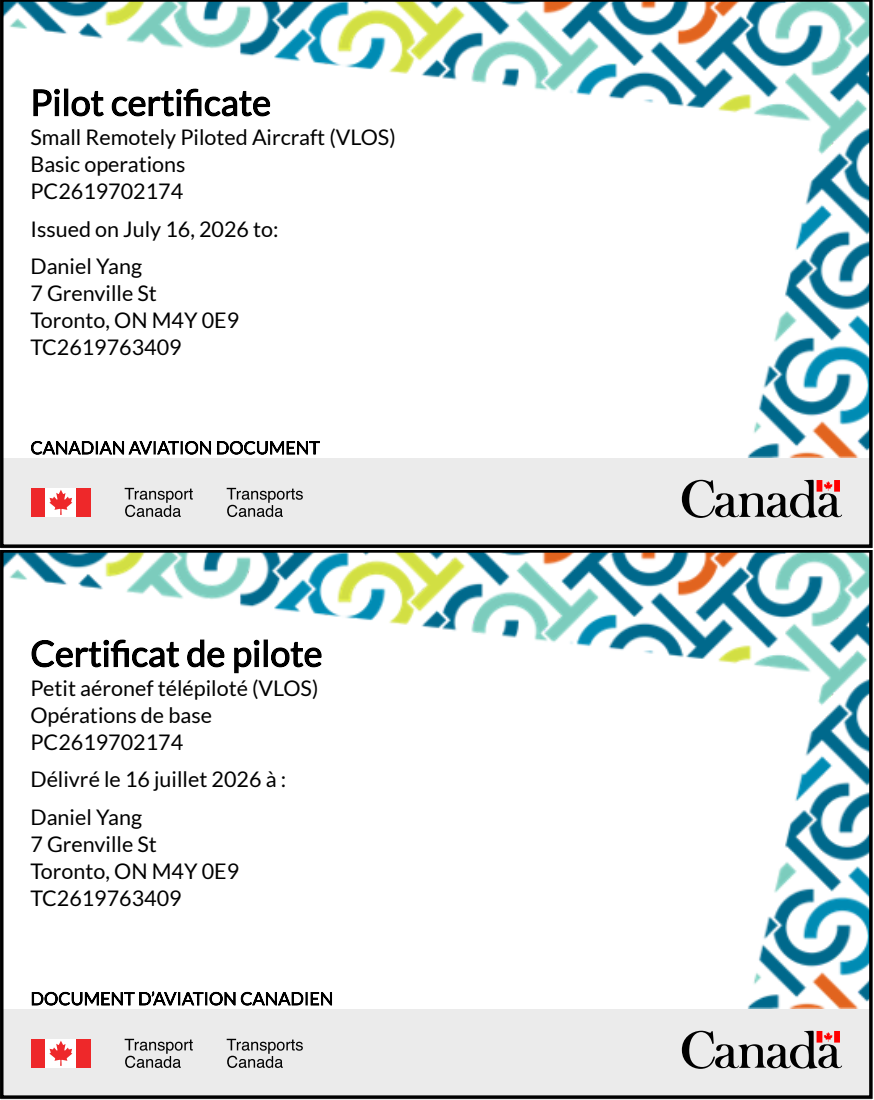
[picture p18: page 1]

Pilot certificate
Small Remotely Piloted Aircraft (VLOS)
Basic operations
Issued on July 16, 2026 to:
Daniel Yang
7 Grenville St
Toronto, ON M4Y 0E9

CANADIAN AVIATION DOCUMENT

Certificat de pilote
Petit aéronef télépiloté (VLOS)
Opérations de base
Délivré le 16 juillet 2026 à :

DOCUMENT D’AVIATION CANADIEN

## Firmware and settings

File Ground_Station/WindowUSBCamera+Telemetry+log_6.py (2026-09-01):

import cv2
import numpy as np
import time
import threading
from dataclasses import dataclass, field
from datetime import datetime
from pathlib import Path
import math
from collections import deque

import matplotlib.pyplot as plt
from openpyxl import Workbook
from openpyxl.chart import LineChart, Reference
from openpyxl.styles import Font, Alignment
from pymavlink import mavutil


# =========================
# USB camera settings
# =========================
CAMERA_INDEX = 1
WINDOW_NAME = "USB Camera"
CAMERA_RECONNECT_INTERVAL = 2.0


# =========================
# MAVLink telemetry settings
# =========================
TELEMETRY_PORT = "COM8"
TELEMETRY_BAUD = 57600

TELEMETRY_RECONNECT_INTERVAL = 3.0
HEARTBEAT_TIMEOUT = 3.0
RC_SIGNAL_TIMEOUT = 2.0

# Re-send MAVLink message-rate requests periodically after connection.
# This fixes the startup-order case where Python starts before the Pixhawk/
# telemetry radio has fully finished booting.
MESSAGE_REQUEST_RETRY_INTERVAL = 3.0

# Your four motors are connected to outputs 9, 10, 11 and 12.
MOTOR_OUTPUT_CHANNELS = (9, 10, 11, 12)

# ArduPilot reports commanded motor output on a 1000-2000 scale.
OUTPUT_MIN = 1000
OUTPUT_MAX = 2000


# =========================
# Logging settings
# =========================
LOG_SAMPLE_INTERVAL = 0.1  # 10 samples per second

# This assumes the script is inside:
# Code/HUD/Control.py
# and logs should be stored inside:
# Code/Log/
BASE_LOG_DIRECTORY = (
    Path(__file__).resolve().parent.parent / "Log"
)


# =========================
# HUD layout settings
# =========================

# Empty border around the normal HUD.
# Normal green HUD graphics will not be copied into this margin.
HUD_SAFE_MARGIN = 25

# Compass may extend below the bottom of the screen.
# 0   = compass bottom touches the screen bottom
# 20  = compass extends 20 px below the screen
# 40  = compass extends 40 px below the screen
COMPASS_DOWN_OFFSET = 10


# =========================
# HUD alert thresholds
# =========================
# TEL / RC:
#   GREEN  >= warning threshold
#   YELLOW between warning and critical
#   RED    < critical
TEL_WARNING_PERCENT = 40
TEL_CRITICAL_PERCENT = 20

RC_WARNING_PERCENT = 40
RC_CRITICAL_PERCENT = 20

# 4S LiPo total voltage:
#   GREEN  >= 14.0 V
#   YELLOW 13.2 V .. <14.0 V
#   RED    < 13.2 V
BAT_VOLTAGE_WARNING = 14.0
BAT_VOLTAGE_CRITICAL = 13.2

# Total aircraft current:
#   GREEN  <= 60 A
#   YELLOW >60 A .. <=90 A
#   RED    >90 A
CURRENT_WARNING_A = 60.0
CURRENT_CRITICAL_A = 90.0

# GPS is only GREEN / RED.
# GREEN requires all three:
#   fix_type >= 3
#   satellites > 3
#   HDOP <= 2.0
GPS_MIN_FIX_TYPE = 3
GPS_MIN_SATELLITES_EXCLUSIVE = 3
GPS_MAX_HDOP = 2.0

# Critical warning text blink period.
WARNING_BLINK_PERIOD_S = 1.0

# Manual HUD alert test:
#   Ctrl + 0 = normal live thresholds / reset
#   Ctrl + 1 = force TEL / RC / CUR / BAT into YELLOW warning state
#   Ctrl + 2 = force TEL / RC / CUR / BAT into RED critical state
#
# The OpenCV HUD window must be active.


@dataclass
class TelemetryState:
    connected: bool = False
    status: str = "Telemetry disconnected"

    battery_voltage_v: float | None = None
    battery_remaining_percent: int | None = None
    total_current_a: float | None = None

    # Link-quality readouts for the lower-left status panel.
    #
    # telemetry_link_quality_percent is calculated locally from MAVLink
    # packet sequence continuity, similar in meaning to Mission Planner's
    # telemetry connection quality percentage.
    telemetry_link_quality_percent: int | None = None
    rc_rssi_percent: int | None = None

    # Main flight HUD values.
    # altitude_m is relative to the home/arming position when available.
    altitude_m: float | None = None
    ground_speed_m_s: float | None = None
    vertical_speed_m_s: float | None = None
    heading_deg: float | None = None

    # GPS status from GPS_RAW_INT.
    # MAVLink fix_type >= 3 means a valid 3D GPS fix.
    gps_fix_type: int | None = None
    gps_satellites_visible: int | None = None
    gps_hdop: float | None = None
    pitch_deg: float | None = None
    roll_deg: float | None = None
    yaw_deg: float | None = None

    motor_percentages: list[float | None] = field(
        default_factory=lambda: [None, None, None, None]
    )

    # Safety-switch/logging state.
    motor_outputs_enabled: bool | None = None
    recording: bool = False
    recording_start_time: float | None = None
    records: list[dict] = field(default_factory=list)
    last_log_sample_time: float = 0.0

    last_heartbeat_time: float = 0.0
    last_rc_message_time: float = 0.0

    # RC receiver state.
    # True  = ArduPilot reports Radio/RC failsafe
    # False = RC receiver is healthy
    # None  = not determined yet
    rc_failsafe: bool | None = None

    lock: threading.Lock = field(default_factory=threading.Lock, repr=False)


def create_no_camera_screen():
    # Keep the fallback black frame when the USB camera is disconnected,
    # but do not draw any "No USB Camera Detected" text.
    screen = np.zeros((480, 640, 3), dtype=np.uint8)
    return screen


def open_usb_camera():
    cap = cv2.VideoCapture(CAMERA_INDEX, cv2.CAP_DSHOW)

    if not cap.isOpened():
        cap.release()
        return None

    return cap


def pwm_equivalent_to_percent(output_value):
    """
    Convert ArduPilot's 1000-2000 motor-output representation to 0-100%.

    This is the commanded output percentage, not actual mechanical RPM.
    """
    if output_value is None or output_value == 0:
        return None

    percentage = (
        (output_value - OUTPUT_MIN)
        / (OUTPUT_MAX - OUTPUT_MIN)
        * 100.0
    )
    

    return max(0.0, min(100.0, percentage))


def request_message_interval(master, message_id, frequency_hz):
    """
    Ask ArduPilot to send a MAVLink message at the requested frequency.
    """
    interval_us = int(1_000_000 / frequency_hz)

    master.mav.command_long_send(
        master.target_system,
        master.target_component,
        mavutil.mavlink.MAV_CMD_SET_MESSAGE_INTERVAL,
        0,
        message_id,
        interval_us,
        0,
        0,
        0,
        0,
        0,
    )


def request_required_messages(master):
    # SYS_STATUS:
    # battery voltage/current and safety-switch state.
    request_message_interval(
        master,
        mavutil.mavlink.MAVLINK_MSG_ID_SYS_STATUS,
        10,
    )

    # BATTERY_STATUS: another source for battery voltage/current.
    request_message_interval(
        master,
        mavutil.mavlink.MAVLINK_MSG_ID_BATTERY_STATUS,
        5,
    )

    # SERVO_OUTPUT_RAW: motor output commands for channels 9-12.
    request_message_interval(
        master,
        mavutil.mavlink.MAVLINK_MSG_ID_SERVO_OUTPUT_RAW,
        10,
    )

    # VFR_HUD: ground speed and heading.
    request_message_interval(
        master,
        mavutil.mavlink.MAVLINK_MSG_ID_VFR_HUD,
        10,
    )

    # GLOBAL_POSITION_INT: altitude relative to home in millimetres.
    request_message_interval(
        master,
        mavutil.mavlink.MAVLINK_MSG_ID_GLOBAL_POSITION_INT,
        10,
    )

    # GPS_RAW_INT: GPS receiver fix status.
    request_message_interval(
        master,
        mavutil.mavlink.MAVLINK_MSG_ID_GPS_RAW_INT,
        5,
    )

    # ATTITUDE: pitch/roll/yaw. We use pitch for the HUD pitch ladder.
    request_message_interval(
        master,
        mavutil.mavlink.MAVLINK_MSG_ID_ATTITUDE,
        20,
    )

    # RC_CHANNELS: receiver RSSI.
    request_message_interval(
        master,
        mavutil.mavlink.MAVLINK_MSG_ID_RC_CHANNELS,
        5,
    )



def close_master(master):
    if master is not None:
        try:
            master.close()
        except Exception:
            pass


def automatic_axis_max(values, minimum_max):
    """
    Calculate a readable automatic y-axis maximum with some headroom.
    """
    valid_values = []

    for value in values:
        if value is None:
            continue

        try:
            numeric_value = float(value)
        except (TypeError, ValueError):
            continue

        if math.isfinite(numeric_value):
            valid_values.append(numeric_value)

    if not valid_values:
        return minimum_max

    data_max = max(valid_values)

    if data_max <= 0:
        return minimum_max

    target = max(data_max * 1.10, minimum_max)

    exponent = math.floor(math.log10(target))
    magnitude = 10 ** exponent
    normalized = target / magnitude

    if normalized <= 1:
        nice_normalized = 1
    elif normalized <= 2:
        nice_normalized = 2
    elif normalized <= 5:
        nice_normalized = 5
    else:
        nice_normalized = 10

    return nice_normalized * magnitude


def save_recording(records):
    """
    Save one recording session to Excel and PNG files.

    All filenames use Control instead of MissionPlanner.
    """
    if not records:
        print("No log data was collected. Nothing was saved.")
        return

    session_name = datetime.now().strftime("%Y-%m-%d_%H-%M-%S")
    session_directory = BASE_LOG_DIRECTORY / session_name
    session_directory.mkdir(parents=True, exist_ok=True)

    excel_path = session_directory / "Control_Log.xlsx"

    workbook = Workbook()
    worksheet = workbook.active
    worksheet.title = "Control Log"

    headers = [
        "Elapsed Time (s)",
        "Computer Time",
        "Battery Current (A)",
        "Motor 1 (%)",
        "Motor 2 (%)",
        "Motor 3 (%)",
        "Motor 4 (%)",
    ]

    worksheet.append(headers)

    for cell in worksheet[1]:
        cell.font = Font(bold=True)
        cell.alignment = Alignment(horizontal="center")

    for record in records:
        worksheet.append(
            [
                record["elapsed_time_s"],
                record["computer_time"],
                record["current_amps"],
                record["motor_1_percent"],
                record["motor_2_percent"],
                record["motor_3_percent"],
                record["motor_4_percent"],
            ]
        )

    column_widths = {
        "A": 18,
        "B": 24,
        "C": 20,
        "D": 15,
        "E": 15,
        "F": 15,
        "G": 15,
    }

    for column, width in column_widths.items():
        worksheet.column_dimensions[column].width = width

    for row in worksheet.iter_rows(min_row=2):
        row[0].number_format = "0.000"
        row[2].number_format = "0.00"

        for cell in row[3:7]:
            cell.number_format = "0.00"

    # Excel motor chart.
    motor_chart = LineChart()
    motor_chart.title = "Motor Output Commands"
    motor_chart.y_axis.title = "Motor Output (%)"
    motor_chart.x_axis.title = "Elapsed Time (s)"
    motor_chart.height = 10
    motor_chart.width = 20

    motor_data = Reference(
        worksheet,
        min_col=4,
        max_col=7,
        min_row=1,
        max_row=worksheet.max_row,
    )

    time_categories = Reference(
        worksheet,
        min_col=1,
        min_row=2,
        max_row=worksheet.max_row,
    )

    motor_chart.add_data(motor_data, titles_from_data=True)
    motor_chart.set_categories(time_categories)
    worksheet.add_chart(motor_chart, "I2")

    # Excel current chart.
    current_chart = LineChart()
    current_chart.title = "Battery Current"
    current_chart.y_axis.title = "Current (A)"
    current_chart.x_axis.title = "Elapsed Time (s)"
    current_chart.height = 10
    current_chart.width = 20

    current_data = Reference(
        worksheet,
        min_col=3,
        min_row=1,
        max_row=worksheet.max_row,
    )

    current_chart.add_data(current_data, titles_from_data=True)
    current_chart.set_categories(time_categories)
    worksheet.add_chart(current_chart, "I22")

    workbook.save(excel_path)

    elapsed_times = [
        record["elapsed_time_s"]
        for record in records
    ]

    current_values = [
        record["current_amps"]
        for record in records
    ]

    motor_values = [
        [
            record[f"motor_{motor_number}_percent"]
            for record in records
        ]
        for motor_number in range(1, 5)
    ]

    # Individual motor plots.
    for motor_number, values in enumerate(motor_values, start=1):
        y_axis_max = automatic_axis_max(values, minimum_max=10)

        plt.figure(figsize=(10, 5))
        plt.plot(elapsed_times, values)
        plt.title(f"Motor {motor_number} Output")
        plt.xlabel("Elapsed Time (s)")
        plt.ylabel("Motor Output (%)")
        plt.ylim(0, y_axis_max)
        plt.grid(True)
        plt.tight_layout()

        output_path = (
            session_directory
            / f"Control_Log_Motor_{motor_number}.png"
        )

        plt.savefig(output_path, dpi=150)
        plt.close()

    # Combined motor plot.
    all_motor_values = [
        value
        for motor_data_list in motor_values
        for value in motor_data_list
    ]

    all_motor_y_max = automatic_axis_max(
        all_motor_values,
        minimum_max=10,
    )

    plt.figure(figsize=(11, 6))

    for motor_number, values in enumerate(motor_values, start=1):
        plt.plot(
            elapsed_times,
            values,
            label=f"Motor {motor_number}",
        )

    plt.title("All Motor Output Commands")
    plt.xlabel("Elapsed Time (s)")
    plt.ylabel("Motor Output (%)")
    plt.ylim(0, all_motor_y_max)
    plt.grid(True)
    plt.legend()
    plt.tight_layout()

    all_motors_path = (
        session_directory
        / "Control_Log_All_Motors.png"
    )

    plt.savefig(all_motors_path, dpi=150)
    plt.close()

    # Battery-current plot.
    current_y_max = automatic_axis_max(
        current_values,
        minimum_max=5,
    )

    plt.figure(figsize=(10, 5))
    plt.plot(elapsed_times, current_values)
    plt.title("Battery Current")
    plt.xlabel("Elapsed Time (s)")
    plt.ylabel("Current (A)")
    plt.ylim(0, current_y_max)
    plt.grid(True)
    plt.tight_layout()

    current_path = (
        session_directory
        / "Control_Log_Battery_Current.png"
    )

    plt.savefig(current_path, dpi=150)
    plt.close()

    print(f"Control log saved to: {session_directory}")
    print(f"Excel file: {excel_path.name}")


def start_recording(state, now):
    with state.lock:
        state.recording = True
        state.recording_start_time = now
        state.records = []
        state.last_log_sample_time = 0.0

    print("Safety released: Control logging started.")


def stop_recording(state):
    with state.lock:
        state.recording = False
        records_to_save = list(state.records)
        state.records = []
        state.recording_start_time = None

    print("Safety enabled: Control logging stopped.")

    # Save in a separate thread so telemetry reception does not pause.
    save_thread = threading.Thread(
        target=save_recording,
        args=(records_to_save,),
        daemon=True,
    )

    save_thread.start()


def process_safety_state(state, outputs_enabled, now):
    """
    Start logging when the safety switch enables motor outputs.
    Stop and save when the safety switch disables motor outputs again.

    The first received state only initializes the detector. This prevents the
    program from unexpectedly starting a log if it was launched after Safety
    had already been released.
    """
    with state.lock:
        previous_state = state.motor_outputs_enabled
        state.motor_outputs_enabled = outputs_enabled

    if previous_state is None:
        initial_text = (
            "OUTPUTS ENABLED"
            if outputs_enabled
            else "SAFETY ON"
        )
        print(f"Initial safety state: {initial_text}")
        return

    if not previous_state and outputs_enabled:
        start_recording(state, now)

    elif previous_state and not outputs_enabled:
        with state.lock:
            was_recording = state.recording

        if was_recording:
            stop_recording(state)


def append_log_sample_if_needed(state, now):
    with state.lock:
        if not state.recording:
            return

        if state.recording_start_time is None:
            return

        if (
            now - state.last_log_sample_time
            < LOG_SAMPLE_INTERVAL
        ):
            return

        state.last_log_sample_time = now

        motor_values = list(state.motor_percentages)

        record = {
            "elapsed_time_s": now - state.recording_start_time,
            "computer_time": datetime.now().strftime(
                "%Y-%m-%d %H:%M:%S.%f"
            )[:-3],
            "current_amps": state.total_current_a,
            "motor_1_percent": motor_values[0],
            "motor_2_percent": motor_values[1],
            "motor_3_percent": motor_values[2],
            "motor_4_percent": motor_values[3],
        }

        state.records.append(record)




def update_mavlink_packet_quality(
    msg,
    now,
    last_seq_by_source,
    quality_events,
    window_seconds=5.0,
):
    """
    Estimate telemetry link quality from MAVLink packet sequence continuity.

    MAVLink packets from each source contain an 8-bit sequence number.
    If the sequence jumps forward, the missing sequence numbers are counted
    as lost packets.

    A rolling time window is used so the displayed percentage responds to
    recent link quality instead of being an all-time average.

    Returns:
        int 0..100 when enough information is available, otherwise None.
    """
    try:
        seq = int(msg.get_seq()) & 0xFF
        src_system = int(msg.get_srcSystem())
        src_component = int(msg.get_srcComponent())
    except Exception:
        return None

    source_key = (
        src_system,
        src_component,
    )

    previous_seq = last_seq_by_source.get(source_key)
    last_seq_by_source[source_key] = seq

    # First packet from a source establishes the baseline.
    if previous_seq is None:
        quality_events.append(
            (
                now,
                1,  # received
                0,  # lost
            )
        )
    else:
        delta = (seq - previous_seq) & 0xFF

        # delta == 0 can be a duplicate packet.
        # Very large deltas usually indicate a reset/out-of-order stream rather
        # than hundreds of genuinely lost packets, so re-baseline instead.
        if delta == 0:
            pass
        elif 1 <= delta <= 127:
            lost_packets = max(
                0,
                delta - 1,
            )

            quality_events.append(
                (
                    now,
                    1,
                    lost_packets,
                )
            )
        else:
            # Sequence moved backwards/reset; do not treat it as massive loss.
            quality_events.append(
                (
                    now,
                    1,
                    0,
                )
            )

    cutoff = now - window_seconds

    while (
        quality_events
        and quality_events[0][0] < cutoff
    ):
        quality_events.popleft()

    received_total = sum(
        event[1]
        for event in quality_events
    )

    lost_total = sum(
        event[2]
        for event in quality_events
    )

    expected_total = (
        received_total
        + lost_total
    )

    if expected_total <= 0:
        return None

    quality = (
        received_total
        / expected_total
        * 100.0
    )

    return int(round(
        max(
            0.0,
            min(
                100.0,
                quality,
            ),
        )
    ))
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

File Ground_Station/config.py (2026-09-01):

from pathlib import Path

############USB Camera Settings
CAMERA_INDEX = 1 #USB Camera index
WINDOW_NAME = "HUD Window"
CAMERA_RECONNECT_INTERVAL = 2.0 


############ MAVLink Telemetry Settings
TELEMETRY_PORT = "COM8"
TELEMETRY_BAUD = 57600
TELEMETRY_RECONNECT_INTERVAL = 3.0
HEARTBEAT_TIMEOUT = 6.0 #Three seconds to check for heartbeat
RC_SIGNAL_TIMEOUT = 2.0
MESSAGE_REQUEST_RETRY_INTERVAL = 15.0
############Motor Settings
MOTOR_OUTPUT_CHANNELS = (9, 10, 11, 12) #Motor1-> channel 9, Motor2->channel 10, Motor3-> channel 11, Motor4-> Channel 12
OUTPUT_MIN = 1000
OUTPUT_MAX = 2000

############# Logging settings
LOG_SAMPLE_INTERVAL = 0.1
PROJECT_ROOT = Path(__file__).resolve().parent
BASE_LOG_DIRECTORY = PROJECT_ROOT / "logs"

############# HUD layout settings
HUD_SAFE_MARGIN = 25
COMPASS_DOWN_OFFSET = 10

############# HUD alert thresholds
TEL_WARNING_PERCENT = 40
TEL_CRITICAL_PERCENT = 20
RC_WARNING_PERCENT = 40
RC_CRITICAL_PERCENT = 20

BAT_VOLTAGE_WARNING = 14.0
BAT_VOLTAGE_CRITICAL = 13.2

CURRENT_WARNING_A = 60.0
CURRENT_CRITICAL_A = 90.0

GPS_MIN_FIX_TYPE = 3
GPS_MIN_SATELLITES_EXCLUSIVE = 3
GPS_MAX_HDOP = 2.0

WARNING_BLINK_PERIOD_S = 1.0

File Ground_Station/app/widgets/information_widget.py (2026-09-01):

import math
import time

from PySide6.QtCore import Qt, QTimer
from PySide6.QtGui import (
    QColor,
    QFont,
    QPainter,
    QPen,
)
from PySide6.QtWidgets import QWidget

from app.widgets.flight_status import FlightStatusWidget


class InformationWidget(QWidget):

    def __init__(self, parent=None, telemetry_state=None):
        super().__init__(parent)

        self.telemetry_state = telemetry_state

        # =====================================================
        # DATA
        # Values remain unavailable until real telemetry is received.
        # =====================================================

        # Data order:
        # [M1, M2, M3, M4]
        self.motor_values = [
            None,
            None,
            None,
            None,
        ]

        # Drone
        self.battery_voltage = None
        self.output_current = None
        self.thrust_loss_motors = set()

        # R-Pi
        self.pi_thr = None
        self.pi_temp = None
        self.pi_load = None

        # PC
        self.pc_battery = None
        self.pc_power_plugged = None
        self.panel_test_alert_mode = 0

        # Independent flight-stage/checklist and warning panel displayed in
        # the right half.  paintEvent() deliberately reserves this area.
        self.flight_status_widget = FlightStatusWidget(self)

        if telemetry_state is not None:
            self.flight_status_widget.bind_telemetry_state(telemetry_state)

        # Qt widgets must be updated on the GUI thread. The timer copies a
        # locked snapshot from the telemetry worker's shared state.
        self.telemetry_timer = QTimer(self)
        self.telemetry_timer.setInterval(200)
        self.telemetry_timer.timeout.connect(self.refresh_from_telemetry)
        self.telemetry_timer.start()

        # =====================================================
        # PANEL SIZE
        # Designed around 400 : 500 minimum
        # =====================================================

        self.setMinimumSize(
            400,
            500,
        )


    # =========================================================
    # DATA UPDATE
    # =========================================================

    def set_telemetry_state(self, telemetry_state):
        """Attach the shared state used by telemetry_worker()."""
        self.telemetry_state = telemetry_state
        self.flight_status_widget.bind_telemetry_state(telemetry_state)
        self.refresh_from_telemetry()


    def bind_telemetry_state(self, telemetry_state):
        """Compatibility entry point used by MainWindow/InstrumentPanel."""
        self.set_telemetry_state(telemetry_state)


    def refresh_from_telemetry(self):
        """Copy all information-panel values from the shared telemetry state."""
        state = self.telemetry_state

        if state is None:
            return

        with state.lock:
            telemetry_connected = bool(getattr(state, "connected", False))
            motor_values = list(getattr(state, "motor_percentages", []))
            battery_voltage = getattr(state, "battery_voltage_v", None)
            output_current = getattr(state, "total_current_a", None)
            pi_thr = getattr(state, "pi_thr", None)
            pi_temp = getattr(state, "pi_temp_c", None)
            pi_load = getattr(state, "pi_load_percent", None)
            pc_battery = getattr(state, "pc_battery_percent", None)
            pc_power_plugged = getattr(state, "pc_power_plugged", None)
            panel_test_alert_mode = int(
                getattr(state, "panel_test_alert_mode", 0)
            )
            thrust_loss_until = dict(
                getattr(state, "potential_thrust_loss_until", {}) or {}
            )

        if telemetry_connected:
            self.motor_values = [
                (
                    None
                    if index >= len(motor_values)
                    or motor_values[index] is None
                    else float(motor_values[index])
                )
                for index in range(4)
            ]
            self.battery_voltage = (
                None
                if battery_voltage is None
                else float(battery_voltage)
            )
            self.output_current = (
                None
                if output_current is None
                else float(output_current)
            )
            self.pi_thr = None if pi_thr is None else int(pi_thr)
            self.pi_temp = None if pi_temp is None else float(pi_temp)
            self.pi_load = None if pi_load is None else float(pi_load)
            now = time.monotonic()
            self.thrust_loss_motors = {
                int(motor_number)
                for motor_number, expiry_time in thrust_loss_until.items()
                if float(expiry_time) >= now
            }
        else:
            # Never leave stale aircraft/Pi values on screen after heartbeat
            # loss. PC power remains local and continues updating separately.
            self.motor_values = [None, None, None, None]
            self.battery_voltage = None
            self.output_current = None
            self.pi_thr = None
            self.pi_temp = None
            self.pi_load = None
            self.thrust_loss_motors = set()

        self.pc_battery = (
            None if pc_battery is None else float(pc_battery)
        )
        self.pc_power_plugged = pc_power_plugged
        self.panel_test_alert_mode = max(
            0,
            min(2, panel_test_alert_mode),
        )

        self.update()

    def set_drone_data(
        self,
        motor_values,
        battery_voltage,
        output_current,
    ):

        self.motor_values = list(
            motor_values
        )

        self.battery_voltage = (
            battery_voltage
        )

        self.output_current = (
            output_current
        )

        self.update()


    def set_pi_data(
        self,
        pi_thr,
        pi_temp,
        pi_load,
    ):

        self.pi_thr = None if pi_thr is None else int(pi_thr)
        self.pi_temp = None if pi_temp is None else float(pi_temp)
        self.pi_load = None if pi_load is None else float(pi_load)

        self.update()


    def set_pc_battery(
        self,
        battery_percent,
    ):

        self.pc_battery = (
            None
            if battery_percent is None
            else float(battery_percent)
        )

        self.update()


    # =========================================================
    # MOTOR GAUGE
    # =========================================================

    def draw_motor_gauge(
        self,
        painter,
        center_x,
        center_y,
        radius,
        value,
        label,
        warning=False,
    ):

        value_available = value is not None
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

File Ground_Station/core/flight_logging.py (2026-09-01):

"""Ground-station recording of Flight Display, HUD and raw USB camera."""

from __future__ import annotations

import json
import os
import shutil
import time
import re
from datetime import datetime
from pathlib import Path

import cv2
import numpy as np
from PySide6.QtCore import QCoreApplication, QObject, QTimer, Slot
from PySide6.QtGui import QImage

from config import BASE_LOG_DIRECTORY


VIDEO_FPS = 10.0
VIDEO_TIMER_INTERVAL_MS = int(round(1000.0 / VIDEO_FPS))
VIDEO_CODEC = "mp4v"
PENDING_SESSION_FILENAME = ".pending_session.json"
GROUND_SESSION_MARKER_FILENAME = ".ground_session.json"
FLIGHT_COUNTER_FILENAME = ".flight_counter.json"
DISARM_PHASE_SETTLE_SECONDS = 5.0
DISARM_MINIMUM_WAIT_SECONDS = 2.5


def _new_session_name():
    log_root = Path(BASE_LOG_DIRECTORY).resolve()
    log_root.mkdir(parents=True, exist_ok=True)
    counter_path = log_root / FLIGHT_COUNTER_FILENAME
    last_sequence = 0
    try:
        payload = json.loads(counter_path.read_text(encoding="utf-8"))
        last_sequence = max(0, int(payload.get("last_flight_sequence", 0)))
    except (OSError, ValueError, TypeError, AttributeError):
        pattern = re.compile(r"^flight_(\d{6})_")
        for path in log_root.iterdir():
            match = pattern.match(path.name)
            if match:
                last_sequence = max(last_sequence, int(match.group(1)))

    sequence = last_sequence + 1
    temporary = counter_path.with_suffix(".json.tmp")
    temporary.write_text(
        json.dumps({"last_flight_sequence": sequence}, indent=2),
        encoding="utf-8",
    )
    os.replace(temporary, counter_path)
    stamp = datetime.now().strftime("%Y-%m-%d_%H-%M-%S")
    return f"flight_{sequence:06d}_{stamp}"


def start_recording(state, now):
    """Telemetry-thread request to begin a three-video session."""
    with state.lock:
        if state.recording:
            return
        # Allocate a counter only after this ARM transition has been accepted.
        # Repeated callbacks while recording must not silently consume numbers.
        session_name = _new_session_name()
        state.recording = True
        state.recording_start_time = now
        state.recording_session_name = session_name
        state.records = []
        state.last_log_sample_time = 0.0
    print(f"Aircraft armed: video recording requested ({session_name}).")


def stop_recording(state):
    """Telemetry-thread request to finish the active video session."""
    with state.lock:
        if not state.recording:
            return
        state.recording = False
        state.recording_start_time = None
    print("Aircraft disarmed: video recording stop requested.")


def process_safety_state(state, outputs_enabled, now):
    """Compatibility hook used by telemetry.py; recording follows ARM state."""
    with state.lock:
        state.motor_outputs_enabled = outputs_enabled
        armed = bool(getattr(state, "armed", False))
        previous_armed = getattr(state, "video_logging_armed", None)
        state.video_logging_armed = armed
        currently_recording = bool(getattr(state, "recording", False))

    if previous_armed is None:
        if armed and not currently_recording:
            start_recording(state, now)
        return
    if not previous_armed and armed:
        start_recording(state, now)
    elif previous_armed and not armed:
        stop_recording(state)


def append_log_sample_if_needed(state, now):
    """Legacy hook: Windows logging is video-only, so no data samples."""
    return


def _qwidget_frame(widget):
    if widget is None or widget.width() <= 0 or widget.height() <= 0:
        return None
    pixmap = widget.grab()
    if pixmap.isNull():
        return None
    image = pixmap.toImage().convertToFormat(QImage.Format_RGBA8888)
    width, height = image.width(), image.height()
    if width <= 0 or height <= 0:
        return None
    rgba = np.frombuffer(
        image.constBits(), dtype=np.uint8, count=image.sizeInBytes()
    ).reshape((height, image.bytesPerLine() // 4, 4))[:, :width]
    return cv2.cvtColor(rgba, cv2.COLOR_RGBA2BGR)
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

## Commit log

2026-09-01 Upload Red Sun quadcopter project
    [Drone FDCR (1).xlsx]
2026-09-01 Organize software and add CAD files
    [5V Wire.SLDPRT, APC 12x6 EP Prop.SLDPRT, Antenna.SLDASM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]
2026-09-01 Add Raspberry Pi flight FSM
2026-09-01 Revise README for Rising Sun Summer Drone project
    Updated project description and details for the Rising Sun Summer Drone, including components, ground station features, CAD files, and onboard system functionality.
2026-09-02 Improve CSV row filtering by removing NUL padding
    Updated CSV processing to remove NUL padding from rows.
